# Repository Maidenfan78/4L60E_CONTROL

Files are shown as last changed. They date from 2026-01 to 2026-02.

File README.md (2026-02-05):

# 4L60-E Manual Mode Transmission Controller

Standalone **manual-mode** transmission controller for a GM **4L60-E**, designed to work alongside a **MegaSquirt 3 ECU (MS3 + MS3X)**.

There is **no automatic shifting**.  
All gear changes are commanded directly by the **T-bar range selector (1 / 2 / 3 / D)**.

The system uses:
- **Teensy 4.1** for real-time transmission control
- **Raspberry Pi Zero 2 W** for logging, tuning, and remote access
- **UART** communication between controller and logger. CP2102 USB–TTL adapter

This architecture prioritizes:
- deterministic real-time behavior
- transmission safety
- simplicity and robustness
- extensibility for future features

Pressure switch manifold feedback is strongly recommended as a safety cross-check.

---

## Vehicle / Powertrain

- **Engine:** Holden Alloytec 3.6L V6  
- **ECU:** MegaSquirt 3 + MS3X Expansion  
- **Throttle Body:** Converted from DBW (Drive-by-Wire) to DVC (Drive-by-Cable)  
- **Transmission:** GM 4L60-E (stock valve body)  
- **Shifter:** T-bar (1 / 2 / 3 / D)

---

## Project Goals

- Manual-only gear control
- Stock valve body retained
- Safe EPC (line pressure) control
- Optional torque converter lockup
- Independent transmission operation (no reliance on Pi)
- Logging and configuration via SSH or USB

EPC control assumption for this project: **PWM duty increases EPC current and reduces line pressure**.
Failsafe behavior is **0% duty = max pressure**.

---

## High-Level Architecture

```text
MegaSquirt 3 ECU (TPS / RPM / CAN / Analog)
            |
            v
Teensy 4.1 (TCM / Controller)
- SSA / SSB
- EPC PWM
- TCC enable + TCC PWM
- VSS capture
- Safety + watchdog
            |
            v
          4L60-E

      UART telemetry/config
            |
            v
Raspberry Pi Zero 2 W (Logger/UI)
- SSH
- Logs
- Config
- (optional) UI
```

---

## Documentation Structure

- **README.md** – Project overview (this file)
- **HARDWARE.md** – Electrical architecture, I/O, drivers
- **FIRMWARE.md** – Control logic, state machines, safety rules
- **TODO.md** – Current build plan and next steps
- **CALIBRATION_NOTES.md** – Vehicle-specific sensor calibration data
- **PRESSURE_SWITCH_VERIFICATION.md** – Step-by-step guide to verify pressure switch truth table

---

## Firmware Workspace

Firmware sources and build config live in `firmware/`.

- **PlatformIO** project targeting Teensy 4.1
- Module layout under `firmware/src/` with headers in `firmware/include/`

Build + upload (from repo root):

```bash
pio run -d firmware
pio run -d firmware -t upload
```

---

## Status

Architecture defined.  
Next steps:
- Hardware pin mapping
- Solenoid driver design
- Firmware skeleton

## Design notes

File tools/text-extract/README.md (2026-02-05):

# Text extraction helpers (optional)

These scripts are optional utilities to make `resources/` searchable (QMD or otherwise) by generating `.txt` sidecar files next to PDFs/images.

## PDF -> text (recommended)

Install Poppler (brings `pdftotext`). On Windows you can:
- `choco install poppler` (if you use Chocolatey)
- or download Poppler binaries and add to PATH

Then run:

```powershell
./pdf-to-text.ps1 -Root "C:\Users\Sav\ProgramingProjects\4l60e_control\resources"
```

This creates `*.pdf.txt` files next to each PDF.

## Image -> text (OCR)

Install Tesseract:

```powershell
choco install tesseract
```

Then run:

```powershell
./image-to-text.ps1 -Root "C:\Users\Sav\ProgramingProjects\4l60e_control\resources" -Force
```

Notes:
- OCR quality varies on wiring diagrams. Even rough text helps search.
- Default skip: images > 8MB (tweak with `-MaxFileMb`).

## Notes

- Keep sidecars small and close to source file.
- Don’t overwrite manually curated notes.

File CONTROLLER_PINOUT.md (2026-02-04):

# Controller Connector Pinout

External connector pinout for the 4L60E TCM controller enclosure.
Two panel-mount connectors separate high-current solenoid circuits from low-current signals.

---

## Connector 1 — Transmission (18 pins)

All wires run to/from the transmission case connector, VSS sensor, and pressure switches.
Solenoid returns are low-side MOSFET switched outputs — current flows from the +12V feed through the solenoid and returns through these pins to ground on the PCB.

| Pin | Wire | Direction | Notes |
| --- | ---- | --- | ----- |
| 1 | SSA return | Out | Shift solenoid A, low-side switched |
| 2 | SSB return | Out | Shift solenoid B, low-side switched |
| 3 | EPC return | Out | EPC solenoid, PWM low-side switched |
| 4 | TCC return | Out | TCC solenoid, low-side switched |
| 5 | TCC PWM return | Out | TCC PWM solenoid, PWM low-side switched (diode flyback) |
| 6 | +12V solenoid feed | — | Ignition-switched, fused, to solenoid common |
| 7 | +12V solenoid feed | — | Parallel pin for current capacity |
| 8 | Power ground | — | Solenoid return current path |
| 9 | Power ground | — | Solenoid return current path |
| 10 | Power ground | — | Solenoid return current path |
| 11 | Pressure switch A | In | Ground-switched, 10k pullup to 3.3V on PCB |
| 12 | Pressure switch B | In | Ground-switched, 10k pullup to 3.3V on PCB |
| 13 | Pressure switch C | In | Ground-switched, 10k pullup to 3.3V on PCB |
| 14 | TFT sensor signal | In | NTC thermistor, 4.7k pullup to 3.3V on PCB |
| 15 | Sensor ground | — | TFT, pressure switches, dedicated path |
| 16 | VSS signal | In | VR sensor, AC coupled into LM2903P conditioner |
| 17 | VSS reference | In | VR sensor return (not chassis ground) |
| 18 | Spare | — | Future use (3-2 shift solenoid) |

Total: 17 active + 1 spare

## Connector 2 — Vehicle (16 pins)

All wires run to vehicle-side sources: fuse box, cabin switches, engine sensors, and external peripherals.

| Pin | Wire | Direction | Notes |
| --- | ---- | --- | ----- |
| 1 | +12V ignition power | In | Main controller supply, fused at source |
| 2 | +12V ignition power | In | Parallel pin for current capacity |
| 3 | Power ground | — | Run both to same chassis earth point |
| 4 | Power ground | — | Do not join at connector |
| 5 | Brake switch | In | +12V switched, through 33k/8.2k divider on PCB |
| 6 | TPS signal | In | 0–5V from MS3 TPS wire, through 15k/24k divider on PCB |
| 7 | RPM signal | In | 0–12V square wave from MS3 tach, through 30k/10k divider on PCB |
| 8 | Signal ground | — | Return for TPS, RPM, brake dividers |
| 9 | Range selector 1 | In | Ground-switched, 10k pullup to 3.3V on PCB |
| 10 | Range selector 2 | In | Ground-switched, 10k pullup to 3.3V on PCB |
| 11 | Range selector 3 | In | Ground-switched, 10k pullup to 3.3V on PCB |
| 12 | Range selector D | In | Ground-switched, 10k pullup to 3.3V on PCB |
| 13 | UART TX | Out | Teensy Serial2 TX (3.3V TTL), 1k series resistor on PCB |
| 14 | UART RX | In | Teensy Serial2 RX (3.3V TTL), 1k series resistor on PCB |
| 15 | UART ground | — | Dedicated return for external UART device |
| 16 | Spare | — | Future use |

Total: 15 active + 1 spare

---

## Pin count summary

| Connector | Active | Spare | Total |
| --- | --- | ----- | ----- |
| Transmission | 17 | 1 | 18 |
| Vehicle | 15 | 1 | 16 |
| Overall | 32 | 2 | 34 |

---

## Build notes

### Grounding rules

- **Power grounds** (Conn 1 pins 8–10, Conn 2 pins 3–4): carry solenoid and controller supply current. Run as separate wires all the way to the chassis earth stud — do not join them at or near the connector.
- **Sensor ground** (Conn 1 pin 15): carries only milliamps from TFT, pressure switches. Runs a dedicated wire back to the PCB signal ground. On the PCB, sensor ground and power ground meet at a single star point near the Teensy ground pin.
- **Signal ground** (Conn 2 pin 8): return path for the voltage divider networks (TPS, RPM, brake). Same star-point rule applies on the PCB.
- **UART ground** (Conn 2 pin 15): dedicated return for the external UART device. Joins signal ground at the PCB star point. Do not share this pin with other ground returns at the connector end.

### Solenoid wiring

- The +12V solenoid feed (Conn 1 pins 6–7) goes to the transmission case connector and feeds all solenoids internally through the valve body harness. Fuse this wire (5A) close to the power source. Two pins are used to share the current load — join them at the fuse output, not at the connector.
- Solenoid return wires (Conn 1 pins 1–5) each carry up to ~1.1A when energised. The MOSFETs on the PCB switch these to ground.
- TCC PWM return (Conn 1 pin 5) is the progressive converter clutch apply solenoid. Uses PWM low-side switching with diode flyback (same topology as EPC) for smooth engagement.
- When all solenoids are off (SSA OFF, SSB OFF), the transmission defaults to 3rd gear (GM failsafe). This is the safe power-loss state.

### VSS sensor

- The VR sensor is a two-wire AC source — it is NOT ground-referenced. Run both VSS signal and VSS reference as a twisted pair from the sensor to the connector. Do not ground the VSS reference wire to chassis at the transmission end.

### UART breakout

- The external UART port uses Teensy Serial2 (TX2/RX2), independent of the internal Pi-Teensy link on Serial1.
- 3.3V TTL levels only. If connecting to a 5V device, use an external level shifter.
- 1k series resistors on both TX and RX are on the PCB for protection.
- Suitable for: USB-TTL debug adapter, Bluetooth serial module (HC-05/06), dash data logger, or external display.
- Default baud rate: TBD (match firmware Serial2 configuration).

### Input protection

- All external-voltage inputs (brake 12V, TPS 5V, RPM 12V) have resistor dividers and dual BAT85 Schottky clamps on the PCB. The connector carries the raw signal — all conditioning happens on the board.
- Ground-switched inputs (range selector, pressure switches) have 10k pullups to 3.3V on the PCB. The connector just passes the switch wire through.

### Wire gauge recommendations

- Solenoid returns + 12V feed: 18–20 AWG (rated for ~1A continuous per wire)
- Power supply + grounds: 18 AWG minimum (multiple amps through controller supply)
- Sensor and signal wires: 22–24 AWG (milliamp currents)
- VSS twisted pair: 22 AWG shielded (noise rejection for VR sensor)
- UART wires: 22–24 AWG (milliamp currents, keep under 2m for reliable comms)

### Connector selection

- Panel-mount (bulkhead) type connectors rated for automotive vibration.
- Transmission connector (18-pin): 5A+ per pin minimum (solenoid current).
- Vehicle connector (16-pin): 3A+ per pin sufficient (mostly signal level).
- Deutsch DTM or DT series panel-mount are the industry standard for aftermarket ECUs. GX20 aviation style connectors are a cheaper alternative.
- Always use keyed/polarised connectors — a mis-mated plug on a transmission controller can destroy solenoids or the PCB.

### Spare pins

- One spare on the transmission connector allows adding the 3-2 shift solenoid later without changing connectors.
- One spare on the vehicle connector for future expansion (e.g. boost solenoid signal, shift light output).

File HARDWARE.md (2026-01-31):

# Hardware Design – 4L60-E Manual Controller

This document describes the electrical and hardware architecture of the transmission controller.

---

## Core Components

### Real-Time Controller
- **Teensy 4.1**
- 600 MHz ARM Cortex-M7
- 3.3V logic
- Hardware PWM timers
- Interrupt-based VSS capture
- Watchdog support

### Logger / Interface
- **Raspberry Pi Zero 2 W**
- Wi-Fi + Bluetooth
- SSH access
- SD-card based logging
- Optional web UI

---

## Power Architecture

- Vehicle 12V supply (10V cranking to 14.7V charging, transients to 40V+)
- Input protection: F1 (2A fuse) → D1 (VFT4045BP Schottky, reverse polarity) → TVS1 (P6KE18A, transient clamp)
- Separate regulated outputs:
  - **PS1: OKI-78SR-5/1.5-W36E-C** → 5V / 1.5A → Teensy 4.1 VIN + line pressure sensor
  - **PS2: DFR0831** → 5V / 4A → Raspberry Pi Zero 2 W (via GPIO header Pin 2/4)
- Both converters need ≥7V input (≥7.4V at battery after Schottky drop)
- Pi powered through GPIO header, not micro USB (bypasses polyfuse; F1 provides upstream protection)

The Teensy must continue running if the Pi browns out or resets.

---

## Communication

- **Protocol:** UART (3.3V TTL)
- **Baud rate:** TBD (e.g. 115200)
- **Direction:**
  - Teensy → Pi: telemetry
  - Pi → Teensy: validated config updates (optional)

CAN may be added later but is not required.

---

## Transmission Outputs (from Teensy)

All solenoids are driven via **automotive-rated low-side drivers**.

| Output | Function |
|---|---|
| SSA | Shift Solenoid A |
| SSB | Shift Solenoid B |
| EPC | Line pressure control (PWM) |
| TCC | Torque converter clutch (on/off enable) |
| TCC PWM | Progressive converter clutch apply (PWM) |

> Solenoids must **never** be driven directly from MCU pins.

---

## Required Inputs to the Controller

### Mandatory
- **Range Selector** (1 / 2 / 3 / D)
- **Vehicle Speed Sensor (VSS)**
- **Throttle Position (TPS)**  
  (from MS3, analog 0–5V or CAN)
- **Brake Switch**

### Strongly Recommended. These are 100% confirmed to be included.
- **Transmission Temperature Sensor**
- **Engine RPM** (from MS3)
- **Pressure switch manifold** (gear confirmation diagnostics)

### Optional / Future
- Paddle shifters
- Mode selector (street / firm / valet)

---

## Shift Solenoid Truth Table (4L60-E)

| Gear | SSA | SSB |
|-----|-----|-----|
| 1st | ON  | ON  |
| 2nd | OFF | ON  |
| 3rd | OFF | OFF |
| 4th | ON  | OFF |

---

## Hardware Design Notes

- EPC solenoid requires **stable PWM** and sufficient current capacity
- Grounding must be low-impedance and star-routed
- VSS input should be protected and conditioned
- All outputs default to a **safe state** on MCU reset

--- 

## Safety Philosophy

- Loss of logger/UI must not affect transmission control
- Any invalid sensor state → increased line pressure
- Harsh shifts are preferred over clutch slip

---

## Signal Levels & Conditioning

- **VSS**: VR sensors need a conditioner (comparator/zero-cross). Hall sensors can be direct with pull-up.
- **TPS / Line Pressure (0–5V)**: scale to 0–3.3V using a divider (e.g., 15k/24k) and add Schottky clamp diodes + a small series resistor at the MCU pin.
- **Brake / 12V Inputs**: use a divider sized for 15V max (e.g., 47k/12k), plus series resistor and Schottky clamps to 3.3V/GND.

---

Teensy 4.1 – Pin Assignment Table

4L60-E Manual Mode Transmission Controller

Digital Outputs (Solenoids)
Function	Teensy Pin	Type	Notes
Shift Solenoid A (SSA)	Pin 2	Digital OUT	Low-side driver input
Shift Solenoid B (SSB)	Pin 3	Digital OUT	Low-side driver input
Torque Converter Clutch (TCC)	Pin 4	Digital OUT	On/off enable
TCC PWM (Progressive Apply)	Pin 12	PWM OUT	Hardware PWM, smooth lockup
EPC / PCS (Line Pressure)	Pin 5	PWM OUT	Hardware PWM, critical

Why these pins

All are on the same GPIO bank

Clean hardware PWM available on Pin 5

Easy to scope during testing

Digital Inputs
Function	Teensy Pin	Type	Notes
Range Selector – 1	Pin 6	Digital IN	Pulled-up, grounded when active
Range Selector – 2	Pin 7	Digital IN	〃
Range Selector – 3	Pin 8	Digital IN	〃
Range Selector – D	Pin 9	Digital IN	〃
Brake Switch	Pin 10	Digital IN	Active high or low (configurable)
Watchdog / Enable (optional)	Pin 11	Digital IN	Optional safety input

Range selector assumed to be decoded into discrete signals
(preferred over analog decoding for reliability).

Pressure Switch Manifold (Gear Confirmation)
Function	Teensy Pin	Type	Notes
Pressure Switch A	Pin 20	Digital IN	Pulled-up, active low
Pressure Switch B	Pin 21	Digital IN	Pulled-up, active low
Pressure Switch C	Pin 22	Digital IN	Pulled-up, active low

Used for gear confirmation diagnostics and fault detection.

Analog Inputs
Function	Teensy Pin	ADC	Notes
TPS (from MS3)	A0 (Pin 14)	ADC1	0–5V scaled to 3.3V
Transmission Temp	A1 (Pin 15)	ADC1	NTC with pull-up
Optional Line Pressure Sensor	A2 (Pin 16)	ADC1	Future expansion

⚠️ Important:
Teensy 4.1 is 3.3V max on ADC pins.
Any 0–5V signal must be divided or buffered.

Speed / Timing Inputs
Function	Teensy Pin	Type	Notes
Vehicle Speed Sensor (VSS)	Pin 18	Interrupt IN	VR → conditioner, Hall → direct
Engine RPM (optional)	Pin 19	Interrupt IN	From MS3 tach out

Pins 18/19 are ideal because:

Dedicated interrupt capability

High-speed edge capture

Minimal latency

Communication
Function	Teensy Pins	Interface	Notes
UART to Pi	TX1 (Pin 1)	Serial1 TX	Teensy → Pi
UART to Pi	RX1 (Pin 0)	Serial1 RX	Pi → Teensy
USB	USB Port	USB CDC	Firmware + bench testing

UART is preferred in-vehicle.
USB is bench/debug only.

Power & Ground
Signal	Connection	Notes
VIN	5V Regulated	From automotive buck
GND	Star Ground	Shared with drivers
AGND	Sensor Ground	TPS / temp reference
Default Output States (Fail-Safe)
Output	Reset State	Reason
SSA	OFF	Prevent unintended shift
SSB	OFF	Prevent unintended shift
EPC	OFF (0% duty)	Max pressure (project assumption)
TCC	OFF	Prevent stall
TCC PWM	OFF (0% duty)	No progressive apply

These defaults must be enforced in firmware AND hardware pull states.
SSA/SSB OFF corresponds to a 3rd-gear command; this is the defined failsafe gear.

Pin Usage Summary
Category	Pins Used
Digital Outputs	2, 3, 4, 5, 12
Digital Inputs	6–11, 20–22
Analog Inputs	14–16
Interrupt Inputs	18, 19
UART	0, 1

Plenty of pins remain free for:

CAN

paddles

mode switch

pressure sensor

diagnostics LEDs

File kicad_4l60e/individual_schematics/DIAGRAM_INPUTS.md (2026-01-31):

# Input Conditioning Circuits

All outputs go to Teensy 4.1 (3.3V absolute max on GPIO).
For external signals, use divider + series resistor + Schottky clamp diodes to keep pins safe.
Automotive voltage range: 10V cranking, 12.6V resting, 14.7V charging (design for 15V worst case).

## Diagrams (SVG)

- `kicad_4l60e/input_diagrams/tps_input.svg`
- `kicad_4l60e/input_diagrams/brake_input.svg`
- `kicad_4l60e/input_diagrams/trans_temp_input.svg`
- `kicad_4l60e/input_diagrams/line_pressure_input.svg`
- `kicad_4l60e/input_diagrams/rpm_input.svg`
- `kicad_4l60e/input_diagrams/range_selector_input.svg`
- `kicad_4l60e/input_diagrams/pressure_switches_input.svg`
- `kicad_4l60e/vss_input_schematic.svg` (VR VSS)

---

## TPS (Pin A0) - Throttle Position Sensor, 0-5V

```
TPS_IN (0-5V) ---[15k]---+---[24k]--- GND
                          |
                          +---[0.1uF]--- GND
                          |
                          +---[1k]---+--- MCU_TPS_A0
                                   |
                                 [D1] 1N5817 (clamp to GND)
                                   |
                                  GND
                                   |
                                 [D2] 1N5817 (clamp to +3.3V)
                                   |
                                 +3.3V
```
Divider: 24k/(24k+15k) = 0.615 --> 5V in = 3.08V out, 5.25V = 3.23V
Filter: ~100Hz cutoff with 10k and 0.1uF

---

## Brake Switch (Pin 10) - 12V Switched

One side of switch wired to +12V (battery/ignition), other side to TCM input.

```
+12V --- [brake switch] ---[47k]---+---[12k]--- GND
                                   |
                                   +---[1k]---+--- MCU_BRAKE_D10
                                             |
                                           [D3] 1N5817 (clamp to GND)
                                             |
                                            GND
                                             |
                                           [D4] 1N5817 (clamp to +3.3V)
                                             |
                                           +3.3V
```
Divider: 12k/(12k+47k) = 0.203

| Condition | Vin | MCU sees | Logic |
|---|---|---|---|
| Brake OFF | 0V | 0V | LOW |
| Brake ON (cranking) | 10V | 2.03V | HIGH  |
| Brake ON (running) | 14.7V | 2.98V | HIGH  |
| Brake ON (worst case)  | 15V | 3.05V | HIGH  |

All values under 3.3V max. Cranking still reads as solid HIGH.

---

## Trans Temp (Pin A1) - NTC Thermistor

```
+3.3V
  |
[3.3k]  pullup
  |
  +---[0.1uF]--- GND
  |
  +--- MCU_TTEMP_A1
  |
 NTC (from trans)
  |
 GND
```
3.3k pullup + NTC forms voltage divider.
Cold = high resistance = high voltage. Hot = low resistance = low voltage.

Connector (2-pin): Pin 1 = NTC signal, Pin 2 = GND

---

## Line Pressure (Pin A2) - Optional Pressure Transducer

Sensor is 5V powered, outputs 0.5-4.5V. 4.5V exceeds 3.3V max so a divider is needed.

```
+5V ------------ J_LPRESS Pin 1 (sensor power)

Sensor signal --- J_LPRESS Pin 2 ---[15k]---+---[24k]--- GND
(0.5-4.5V)                                  |
                                             +---[0.1uF]--- GND
                                             |
                                             +---[1k]---+--- MCU_LPRESS_A2
                                                       |
                                                     [D5] 1N5817 (clamp to GND)
                                                       |
                                                      GND
                                                       |
                                                     [D6] 1N5817 (clamp to +3.3V)
                                                       |
                                                     +3.3V

GND ------------ J_LPRESS Pin 3 (sensor ground)
```
Divider: 24k/(24k+15k) = 0.615

| Sensor output | MCU sees |
|---|---|
| 0.5V (0 psi)  | 0.31V |
| 2.5V (mid) | 1.54V |
| 4.5V (max) | 2.77V |
| 5.0V (fault)  | 3.08V |

All values under 3.3V max. Filter: ~100Hz cutoff with 10k and 0.1uF.

Connector (3-pin): Pin 1 = +5V, Pin 2 = Signal, Pin 3 = GND

---

## RPM (Pin 19) - Tach from MegaSquirt 3

MS3 tach output is a 0-12V square wave (battery-level). Use a voltage divider to bring it under 3.3V,
then clamp diodes as backup protection.

```
RPM_IN (0-12V sq) ---[47k]---+---[12k]--- GND
                              |
                              +---[1k]---+--- MCU_RPM_D19
                                        |
                                      [D7] 1N5817 (clamp to GND)
                                        |
                                       GND
                                        |
                                      [D8] 1N5817 (clamp to +3.3V)
                                        |
                                      +3.3V
```
Divider: 12k/(12k+47k) = 0.203 --> 12V in = 2.44V out
Schottky clamp diodes are backup only - divider does the real work.
Square wave at ~2.4V is a solid logic HIGH.

Connector (2-pin): Pin 1 = RPM signal, Pin 2 = GND

---

## Range Selector (Pins 6/7/8/9) - T-Bar 1/2/3/D

Each range position has its own wire from the TCM to the switch.
All switches share a common ground on the other side.
Selecting a gear grounds that wire.

```
+3.3V  +3.3V  +3.3V  +3.3V
  |      |      |      |
[10k]  [10k]  [10k]  [10k]   external pullups
  |      |      |      |
  +------+------+------+----- J_RANGE Pin 5 (common GND on switch side)
  |      |      |      |             |
  |      |      |      |           (GND)
  |      |      |      |
  |      |      |      +--- MCU_RNGD_D9  (Drive/4th)
  |      |      +--- MCU_RNG3_D8         (3rd)
  |      +--- MCU_RNG2_D7                (2nd)
  +--- MCU_RNG1_D6                       (1st)
```

Better view - each channel is identical:

```
+3.3V ---[10k]---+--- MCU_RNGx
                  |
           Range switch (normally open)
                  |
                 GND (common ground at switch)
```

- Switch OPEN  = 10k pulls pin HIGH (3.3V) = not selected
- Switch CLOSED = pin pulled to GND          = gear selected
- Only one position active at a time

Connector (5-pin): Pin 1 = Gear 1, Pin 2 = Gear 2, Pin 3 = Gear 3, Pin 4 = Drive, Pin 5 = Common GND

---

## Pressure Switches A/B/C (Pins 20/21/22) - Gear Confirmation

Same topology as range selector. Trans internal switches are ground-switched.

```
+3.3V ---[10k]---+--- MCU_PSW_x
                  |
           Pressure switch (inside trans)
                  |
                 GND (common ground)
```

- Switch OPEN  = HIGH = pressure not present
- Switch CLOSED = LOW  = pressure present

Connector (4-pin): Pin 1 = PSW_A, Pin 2 = PSW_B, Pin 3 = PSW_C, Pin 4 = Common GND

---

## VSS (Pin 18) - Variable Reluctance Speed Sensor with LM2903P

```
                    +3.3V             +3.3V
                     |                   |
                    [10k] bias        [10k] pullup
                     |                   |
VR sensor ---[0.1uF]-+---[D2]---+3.3V    |
  (AC)               |              LM2903P OUT (Pin 1) ---+--- MCU_VSS_D18
                     +---[D1]---GND     |                  |
                     |                  |                [0.1uF] C4
                   [10k] bias       [100k]                 |
                     |              hysteresis             GND
                    GND                |
                     |                 |
                     +--- LM2903P IN(+) Pin 3 -+
                     |
                     +--- LM2903P IN(-) Pin 2 --- same bias point (1.65V)

                    +3.3V (Pin 8)
                       |
                     [0.1uF] C5 (decoupling cap, close to IC)
                       |
                      GND (Pin 4)
```

**LM2903P DIP-8 Pinout:**

- Pin 1: Output (comparator 1) → to MCU via pullup
- Pin 2: IN(-) → 1.65V reference
- Pin 3: IN(+) → biased VR signal
- Pin 4: GND
- Pin 5: IN(+) comparator 2 (NC)
- Pin 6: IN(-) comparator 2 (NC)
- Pin 7: Output comparator 2 (NC)
- Pin 8: VCC (+3.3V)

**Step by step:**

1. **AC coupling**: C3 = 0.1uF blocks DC from VR sensor, passes AC signal
2. **Clamp diodes**: D1 (1N4148) to GND, D2 (1N4148) to +3.3V - limits swing
3. **Bias network**: Two 10k resistors, one to +3.3V and one to GND = 1.65V DC bias
4. **Comparator (-) input (Pin 2)**: Tied to same 1.65V bias point (reference)
5. **Comparator (+) input (Pin 3)**: Biased VR signal - swings above/below 1.65V
6. **Hysteresis**: R9 = 100k from output back to (+) input prevents chatter
7. **Output pullup**: R10 = 10k to +3.3V (LM2903 is open-collector, needs pullup)
8. **Output filter**: C4 = 0.1uF on output cleans up edges
9. **Power**: Pin 8 to +3.3V, Pin 4 to GND, C5 = 0.1uF decoupling cap between them

Connector (2-pin): Pin 1 = VR signal, Pin 2 = VR return / GND

For Hall-effect VSS: skip this circuit, just use 10k pullup to 3.3V directly.

---

## Component Summary

| Part | Value | Qty | Used In |
|---|---|-----|---|
| R | 1k | 4 | Series resistors for TPS, RPM, line pressure, brake |
| R | 10k | 10  | Range (x4), pressure sw (x3), VSS pullup, VSS bias (x2) |
| R | 12k | 2 | Brake divider, RPM divider (bottom resistor) |
| R | 15k | 2 | TPS divider, line pressure divider (top resistor) |
| R | 24k | 2 | TPS divider, line pressure divider (bottom resistor) |
| R | 47k | 2 | Brake divider, RPM divider (top resistor) |
| R | 3.3k | 1 | Temp pullup |
| R | 100k | 1 | VSS hysteresis |
| C | 0.1uF | 6 | TPS, temp, line pressure, VSS coupling (C3), VSS output (C4), VSS decoupling (C5) |
| D | 1N5817  | 8 | TPS clamp (x2), RPM clamp (x2), line pressure clamp (x2), brake clamp (x2) |
| D | 1N4148  | 2 | VSS clamp (x2) |
| IC | LM2903P | 1 | VSS comparator (DIP-8, only comparator 1 used) |

## Pin Summary

| Teensy Pin | Function | Type |
|---|---|---|
| A0 (14) | TPS | Analog 0-3.3V |
| A1 (15) | Trans Temp | Analog (NTC) |
| A2 (16) | Line Pressure | Analog 0.5-4.5V (optional) |
| 6 | Range 1st | Digital, active LOW |
| 7 | Range 2nd | Digital, active LOW |
| 8 | Range 3rd | Digital, active LOW |
| 9 | Range Drive | Digital, active LOW |
| 10 | Brake Switch | Digital, active HIGH |
| 18 | VSS | Digital, interrupt |
| 19 | RPM Tach | Digital, frequency |
| 20 | Pressure Sw A | Digital, active LOW |
| 21 | Pressure Sw B | Digital, active LOW |
| 22 | Pressure Sw C | Digital, active LOW |

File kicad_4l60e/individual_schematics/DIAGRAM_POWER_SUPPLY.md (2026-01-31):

# Power Supply Circuits

Automotive 12V to regulated 5V for Teensy 4.1 and Raspberry Pi Zero 2 W.
Automotive voltage range: 10V cranking, 12.6V resting, 14.7V charging, transients to ~40V.

---

## Power Architecture Overview

```
                                        +--- OKI-78SR-5 ---+--- 5V_TEENSY ---> Teensy 4.1 VIN
                                        |   (5V / 1.5A)    |
VEHICLE +12V ---[F1]---[D1]---[TVS1]---+                   +--- 5V_SENSOR ---> Line pressure sensor
                                        |
                                        +--- DFR0831 ------+--- 5V_PI -------> Pi Zero 2 W
                                            (5V / 4A)

VEHICLE GND -------------------------------- GND (star ground point)
```

Key design rules:
- Teensy and Pi have **separate** buck converters (Teensy must survive Pi brownout)
- Reverse polarity protection **before** both converters
- TVS clamping **before** both converters
- Fuse protects the entire board

---

## Stage 1: Input Protection

```
VEHICLE +12V                                         To buck converters
    |                                                       |
    +---[F1 2A fast-blow]---+---[D1 VFT4045BP]-----+--------+
                            |    (Schottky)        |
                            |    Anode --> Cathode |
                            |                      |
                            |                   [TVS1]  P6KE18A (or SMBJ16A)
                            |                      |
                           GND                    GND
```

### F1 - Input Fuse
- **2A fast-blow** fuse
- Protects against short circuits and reverse polarity (blows if D1 is reverse-biased)
- OKI-78SR datasheet recommends 2A fuse

### D1 - Reverse Polarity Protection (VFT4045BP Schottky)
- 45V, 40A Schottky rectifier
- Forward voltage drop: **0.41V** at 5A (very low loss)
- At 1A typical system draw: ~0.3V drop, so converters see ~12.3V (well above 7V min)
- At cranking (10V): converters see ~9.6V (still above 7V min)
- Blocks reverse polarity completely (fuse blows as backup)

### TVS1 - Transient Voltage Suppression
- **P6KE18A** (or SMBJ16A bidirectional)
- Standoff voltage: 15.3V (won't conduct during normal operation at 14.7V)
- Breakdown: 18V
- Clamps load dump transients (up to 40V+ spikes) to safe levels
- Placed **after** D1 so it only sees forward-polarity transients

### Voltage at converter inputs after protection:

| Condition | Battery | After D1 (Schottky) | TVS clamp |
|---|---|---|---|
| Cranking | 10V | ~9.6V | No clamp  |
| Resting | 12.6V | ~12.2V | No clamp  |
| Charging | 14.7V | ~14.3V | No clamp  |
| Load dump spike | 40V+ | ~39.6V | Clamped to ~18V |

All values within OKI-78SR input range (7-36V).

---

## Stage 2A: Teensy 4.1 Power Supply

```
Protected 12V rail                              To Teensy 4.1
      |                                              |
      +---[Cin 22uF ceramic]---GND          +--------+---[Cout 22uF ceramic]---GND
      |                                     |
      +--- OKI-78SR-5/1.5-W36E-C ---+------+
           Pin 1: +Vin               |
           Pin 2: GND (Common)       |
           Pin 3: +Vout (5V)         |
                                     |
                              5V_TEENSY rail
                                     |
                                     +---> Teensy 4.1 VIN pin
                                     +---> Line pressure sensor +5V (if used)
```

### OKI-78SR-5/1.5-W36E-C
- Input: 7-36V DC (covers full automotive range after Schottky drop)
- Output: **5.0V regulated**, 1.5A max
- Efficiency: ~90% at 12V in
- Short circuit protection (hiccup mode, auto-recovery)
- No heatsink required
- Drop-in replacement for 7805 linear regulator (same pinout)
- Operating temp: -40 to +85C

### Input capacitor (Cin)
- 22uF ceramic, 50V rated
- Placed close to OKI-78SR input pins
- Low ESR type (X5R or X7R)
- Per datasheet: "install a low-ESR capacitor immediately adjacent to input terminals"

### Output capacitor (Cout)
- 22uF ceramic, 10V rated
- Optional per datasheet but recommended for improved transient response
- Do NOT exceed 300uF (low ESR) or 3300uF (higher ESR)

### Load budget (Teensy rail):

| Load | Current |
|---|---|
| Teensy 4.1 | ~100mA |
| Input conditioning (3.3V) | ~5mA |
| LM2903 comparator | ~2mA |
| Line pressure sensor | ~20mA |
| **Total** | **~130mA** |

Well within 1.5A capacity. Teensy's onboard regulator converts 5V to 3.3V for the MCU and I/O.

---

## Stage 2B: Raspberry Pi Power Supply

```
Protected 12V rail                              To Pi Zero 2 W
      |                                              |
      +---[Cin 22uF ceramic]---GND                   |
      |                                     +--------+
      +--- DFR0831 ---- OUT+ ---+-----------+
           IN+                  |            |
           IN-                  |        Pi GPIO Header
           OUT-                 |        Pin 2/4 = +5V
             |                  |        Pin 6 = GND
            GND                 |
                           [Cout2 220uF electrolytic]
                                |
                               GND
```

### DFR0831 DC-DC Buck Converter
- Input: 7-24V DC
- Output: **5.0V regulated**, 4A max (20W)
- Efficiency: ~90%
- Output ripple: <100mV
- Output accuracy: +/-0.1V
- Operating temp: -40 to +85C
- 6 output ports on board (convenient for Pi + accessories)

### Output bulk capacitor (Cout2)

- 220uF electrolytic, 10V rated
- Smooths transient current demands from the Pi (draws current in bursts during boot and CPU/USB activity)
- The DFR0831's onboard caps are small ceramics — the bulk cap supplements them
- Not strictly required but cheap insurance in an automotive environment

### Pi Zero 2 W connection

- Power via **GPIO header** (not micro USB port)
- Pin 2 or Pin 4 = +5V, Pin 6 = GND
- This bypasses the Pi's onboard polyfuse, so the DFR0831's current limit and upstream fuse F1 provide protection
- UART connection to Teensy: Pi GPIO 14 (TX) → Teensy RX1 (Pin 0), Pi GPIO 15 (RX) → Teensy TX1 (Pin 1)
- Both are 3.3V logic — no level shifting needed

### Important note on input range

- DFR0831 max input is **24V** (30V absolute max on PCB marking)
- The TVS clamps transients to ~18V so this is safe
- At charging voltage (14.7V - 0.4V Schottky = 14.3V): well within range
- Without the TVS, automotive load dump could exceed 24V and damage this converter

### Load budget (Pi rail):

| Load | Current |
|---|---|
| Pi Zero 2 W (idle)  | ~100mA |
| Pi Zero 2 W (busy)  | ~350mA |
| Pi Zero 2 W (peak)  | ~500mA |
| Wi-Fi active | +50-100mA  |
| **Total peak** | **~600mA** |

Well within 4A capacity.

---

## Stage 3: Teensy Power Input Detail

```
5V_TEENSY rail
      |
      +---> Teensy 4.1 VIN pin (regulated 5V input)

      Teensy onboard:
      VIN (5V) ---> [onboard 3.3V regulator] ---> 3.3V rail (250mA max)
                                                     |
                                                     +---> MCU (i.MX RT1062)
                                                     +---> GPIO pins (3.3V logic)
                                                     +---> 3.3V output pin
                                                              |
                                                              +---> Input pullups
                                                              +---> VSS bias network
                                                              +---> LM2903 Vcc
```

The Teensy's **onboard 3.3V regulator** supplies:
- The MCU itself
- All GPIO pins (3.3V logic)
- The 3.3V output pin that powers our input conditioning pullups and bias networks
- Total 3.3V load from our circuits: ~5mA (well under 250mA capacity)

---

## Grounding

```
                    STAR GROUND POINT (single PCB location)
                            |
              +-------------+-------------+-------------+
              |             |             |             |
         Power GND     Signal GND    Analog GND    Solenoid GND
              |             |             |             |
         Buck converter  Digital I/O   TPS/Temp ADC   MOSFET drivers
         returns         range sel.    NTC sensor     SSA/SSB/EPC/TCC
                         press. sw.    line pressure
                         brake sw.     VSS bias
```

### Grounding rules:
1. **Single star ground point** on PCB - all ground paths meet here
2. **Analog ground (AGND)** traces kept separate from digital until star point
3. **Solenoid return currents** routed separately - high current PWM noise must not
   couple into signal grounds
4. Teensy AGND pin tied to analog ground trace
5. Teensy GND pins tied to digital/power ground
6. Both connect at the star point

---

## Component Summary

| Part | Value / Part Number | Qty | Function |
|---|---|-----|---|
| F1 | 2A fast-blow fuse | 1 | Input overcurrent protection |
| D1 | VFT4045BP (Schottky) | 1 | Reverse polarity protection |
| TVS1 | P6KE18A | 1 | Transient voltage clamping |
| U_REG1 | OKI-78SR-5/1.5-W36E-C | 1 | 12V to 5V buck (Teensy) |
| U_REG2 | DFR0831 | 1 | 12V to 5V buck (Pi) |
| Cin1 | 22uF ceramic 50V | 1 | OKI-78SR input filter |
| Cout1 | 22uF ceramic 10V | 1 | OKI-78SR output filter |
| Cin2 | 22uF ceramic 50V | 1 | DFR0831 input filter |
| Cout2 | 220uF electrolytic 10V | 1 | DFR0831 output bulk cap |

---

## Cranking / Brownout Behavior

| Event | Battery V | After D1 | OKI-78SR (Teensy) | DFR0831 (Pi) |
|---|---|---|---|---|
| Normal running | 14.0V | 13.6V | 5.0V output OK | 5.0V output OK |
| Key on, engine off | 12.6V | 12.2V | 5.0V output OK | 5.0V output OK |
| Cranking dip | 10.0V | 9.6V | 5.0V output OK | 5.0V output OK |
| Deep crank | 7.5V | 7.1V | 5.0V output OK (min 7V) | 5.0V output OK (min 7V) |
| Severe brownout | 6.5V | 6.1V | **Drops out** | **Drops out** |

Both converters have 7V minimum input. After the ~0.4V Schottky drop, the system needs at
least **7.4V at the battery** to maintain regulation. Below that, both converters will drop out.

The OKI-78SR has hiccup-mode short circuit protection and will auto-recover when voltage
returns. The Teensy will reboot cleanly on power restore.

If the Pi browns out first (due to higher current draw), the Teensy continues running
independently - this is by design. The transmission controller does not depend on the Pi.

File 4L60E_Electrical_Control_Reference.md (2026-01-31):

# 4L60‑E Electrical & Control Reference  
**Solenoids, Sensors, PWM, and Calibration Notes**

This document is a **supplemental technical reference** for a GM **4L60‑E** automatic transmission, intended to be used alongside wiring/pinout documentation.

It focuses on:
- solenoid electrical characteristics
- PWM requirements
- sensor ranges
- practical control notes for standalone controllers (Teensy, MegaShift, etc.)

---

## 1) Solenoid Electrical Characteristics

| Solenoid | Function | Resistance (Ω) | Typical Current | Control Type |
|---|---|---|---|---|
| Shift Solenoid A (SSA) | 1–2 / 3–4 shifts | 20–40 Ω | ~0.5–0.8 A | On/Off |
| Shift Solenoid B (SSB) | 2–3 shifts | 20–40 Ω | ~0.5–0.8 A | On/Off |
| 3–2 Control Solenoid | Coast downshift assist | 9–14 Ω | ~1.0–1.3 A | PWM |
| EPC / PCS Solenoid | Line pressure control | **3.5–4.6 Ω** | **0–1.1 A** (0A=max pressure) | **PWM (critical)** |
| TCC Solenoid | Torque converter lockup (enable) | 20–40 Ω | ~1.0–1.5 A | On/Off |
| TCC PWM Solenoid | Progressive converter clutch apply | 20–40 Ω | ~1.0 A | PWM |
| LUF (if fitted) | Lockup feel modulation | ~10–15 Ω | ~1.0 A | PWM |

**Notes**
- All solenoids are **ground‑switched** (low‑side control).
- EPC solenoid has the **highest thermal load** and must be heatsinked.
- Resistance varies by year/manufacturer; measure if in doubt.

---

## 2) Recommended PWM Frequencies

| Solenoid | PWM Frequency | Notes |
|---|---|---|
| EPC / PCS | **200–300 Hz** (OEM ≈ 293 Hz) | Higher = heat, lower = noise |
| 3–2 Solenoid | ~50 Hz | Only active during coast downshifts |
| LUF | ~30–40 Hz | Optional / transmission dependent |
| TCC (if PWM) | 20–100 Hz | Often used as on/off |

For EPC (exhaust-bleed type):

- Duty cycle ↑ → line pressure ↓ (exhaust open longer)
- Duty cycle ↓ → line pressure ↑ (exhaust open shorter)
- 0% duty = max pressure (failsafe)
- **60% duty is the hard ceiling** — not a comfort limit, but thermal + hydraulic protection
  - At ~4Ω coil resistance, 60% duty limits average current to ~1.1A
  - Never exceed 60% duty even when requesting minimum pressure

---

## 3) EPC (Line Pressure) Control Guidelines

### Pressure Command Abstraction (Recommended)

Use a **Pressure Command %** scale in firmware (0–100%, where 100% = max pressure).
Convert to EPC duty via inversion in one place:

| Pressure Command | EPC Duty (approx) | Result |
|---|---|---|
| 100% (max) | ~5% (near OFF) | Maximum pressure |
| 50% | ~30% | Medium pressure  |
| 0% (min) | ~60% (near max) | Minimum pressure |

This keeps tuning tables intuitive and matches MegaShift conventions.

### Control Rules

- EPC duty must **never rise too high under load** (causes low pressure / slip)
- Conservative tuning is preferred:
  - harsh shifts > clutch slip
- Use a **shift pressure bump**:
  - temporarily raise pressure command during gear changes
- On fault:
  - force **100% pressure command** (0% EPC duty = max pressure)
  - disable TCC

### Typical Pressure Command Ranges

| Condition | Pressure Command |
|---|---|
| Light load cruise| ~30–40% |
| Moderate load | ~45–55% |
| Heavy load / WOT | ~60–75% |
| Shift bump | +15–25% |

(Exact values depend on valve body and calibration.)

### Flyback Suppression for EPC

For **smoother pressure modulation**, use a **diode** (e.g., 1N4001) across the EPC solenoid.
The slower current decay acts as a low-pass filter on pressure changes.

For **SSA/SSB/TCC enable** (on/off solenoids), use **TVS** for faster response.
For **TCC PWM**, use a **diode** (same as EPC) for smooth progressive apply.

---

## 4) Transmission Sensors

### 4.1 Vehicle Speed Sensor (VSS)
- Type: usually **2‑wire VR**
- Signal: AC sine wave
- Requires zero‑crossing or comparator conditioning
- Frequency proportional to output shaft speed

Standalone controllers must:
- condition VR properly
- debounce / filter noise
- detect signal loss

---

### 4.2 Transmission Temperature Sensor
- Type: NTC thermistor (GM style)
- Typical resistance:
  - ~100kΩ cold
  - ~2–5kΩ hot
- Used for:
  - TCC inhibit
  - pressure biasing
  - over‑temp protection

---

### 4.3 Line Pressure Sensor (optional)
- Type: 0.5–4.5 V transducer
- Supply: 5 V reference
- Range: commonly 0–300 psi
- Very useful for EPC tuning

---

### 4.4 Pressure Switch Manifold (Manual Valve Position)

The pressure switches report hydraulic state of the manual valve.

| Gear | Switch A | Switch B | Switch C |
|----|----|----|----|
| 1st | 0 | 1 | 1 |
| 2nd | 1 | 1 | 1 |
| 3rd | 1 | 1 | 0 |
| 4th | 1 | 0 | 0 |
| Reverse | 0 | 0 | 1 |
| Neutral / Park | 0 | 0 | 0 |

These can be used as:
- sanity checks
- limp‑mode detection
- diagnostics

---

## 5) TCC (Torque Converter Clutch) Notes

- Lockup only recommended in **3rd and 4th**
- Always unlock:
  - during shifts
  - on brake input (immediate)
  - at high TPS
  - during throttle transients
  - during faults
- Use **delay timer before lockup** — prevents lock/unlock cycling
- Hysteresis matters more than fancy logic
- TCC must never fight EPC or gear changes
- TCC PWM progressive apply ramps clutch pressure gently to avoid shudder
- TCC enable (on/off) energises first, then TCC PWM ramps up
- On unlock: TCC PWM drops to 0% immediately, then TCC enable turns off

---

## 6) Electrical & Grounding Notes

- Solenoids must have:
  - dedicated high‑current ground returns
  - separate sensor ground
- Avoid shared grounds between:
  - EPC return
  - TPS / temp sensors
- Use star grounding at controller enclosure

---

## 7) Standalone Controller Safety Rules (Recommended)

- Default state on reset:
  - SSA OFF, SSB OFF (3rd gear — intentional GM limp mode)
  - max line pressure (0% EPC duty)
  - TCC off (enable OFF, PWM 0%)
- **0% EPC duty (max pressure) triggers:**
  - MCU reset / watchdog timeout
  - sensor loss (TPS, VSS)
  - over-temperature
  - any fault condition
- Loss of VSS:
  - inhibit downshifts
  - inhibit TCC
- Over‑temperature:
  - disable TCC
  - raise line pressure
- MCU watchdog enabled at all times

---

## 8) Practical Tuning Advice

- Start with **fixed high pressure**
- Verify correct gear engagement
- Add TPS‑based pressure mapping
- Add shift pressure bump
- Enable TCC last

---

## 9) Intended Use

This document is intended to support:
- Teensy‑based TCM projects
- MegaShift / GPIO‑style controllers
- Manual‑mode or paddle‑shift 4L60‑E builds

Improper control of automatic transmissions can cause damage or injury.  
Proceed carefully and test incrementally.

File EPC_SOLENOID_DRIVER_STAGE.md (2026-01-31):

EPC + Solenoid Driver Stage

4L60-E | Teensy 4.1 | Automotive-safe

1️⃣ Design philosophy (important)

Low-side switching (OEM-correct for GM)

MCU never drives solenoids directly

EPC must survive continuous PWM

Fail-safe bias = MAX pressure

Flyback suppression that won’t kill MOSFETs

Survives load dump, inductive kick, noise

2️⃣ Solenoids to drive
Solenoid	Type	Control
SSA	On/Off	Digital
SSB	On/Off	Digital
TCC	On/Off enable	Digital
TCC PWM	PWM progressive apply	PWM (20-100 Hz)
EPC / PCS	PWM, current-controlled-ish	Critical

EPC current range: **0–1.1 A** (0A = max pressure, ~1.1A = min pressure), continuous PWM.

3️⃣ Recommended topology (one channel)

All solenoids use the same base topology, EPC just needs better thermal handling.

+12V ---- Solenoid ---- Drain MOSFET Source ---- GND
                      |
                      +-- Flyback clamp (TVS)
Gate ← Gate resistor ← Teensy pin
         |
        Gate pulldown

4️⃣ MOSFET selection (do NOT cheap out)
Recommended MOSFET (proven automotive choice)

**STP36NF06L** (ST Microelectronics)

- 60V VDS
- 30A ID (continuous)
- 40mΩ RDS(on) max @ VGS=10V
- Logic-level gate (VGS(th) 1.0–2.5V, 3.3V compatible)
- Low gate charge (13–17nC)
- **AEC-Q101 automotive qualified**
- TO-220 package (hand-solderable)

Good alternatives:

- Infineon BSC010NE2LS5 (SMD)
- IPB044N06L3

⚠️ Avoid random eBay MOSFETs.

5️⃣ Gate drive network (critical for noise immunity)
Gate components (per solenoid)
Component	Value	Purpose
Gate resistor	100 Ω	Limits inrush, reduces ringing
Gate pulldown	100 kΩ	Ensures OFF at reset
MCU pin	3.3V	Teensy compatible

Why this matters

Prevents accidental turn-on during reset

Controls EMI

Improves MOSFET longevity

6️⃣ Flyback protection (THIS IS NOT OPTIONAL)

### For SSA / SSB / TCC (on/off solenoids)

Use **bidirectional TVS** across solenoid:

- Recommended: **5KP36CA** (36V clamp, 5000W peak pulse, axial) or SMBJ36CA (SMD)
- Connection: Drain ─── TVS ─── +12V

This allows:

- fast current decay
- controlled voltage spike
- crisp solenoid release

### For EPC (PWM pressure control)

Use a **diode** (e.g., **1N4001** or 1N4007) across the EPC solenoid:

- Connection: Cathode to +12V, Anode to Drain
- The slower current decay acts as a **low-pass filter** on pressure
- Results in **smoother pressure modulation**

This matches MegaShift recommendations for "greater line pressure control."

Optionally add a small TVS (5KP36CA) in parallel for spike protection.

| Solenoid | Flyback Type | Reason |
|---|---|---|
| SSA | TVS | Fast response for shifts |
| SSB | TVS | Fast response for shifts |
| TCC | TVS | Crisp lockup engagement |
| TCC PWM  | Diode | Smooth progressive apply |
| EPC | Diode (+TVS) | Smooth pressure modulation |

7️⃣ EPC PWM specifics (very important)
PWM frequency

Recommended: 200–300 Hz

Matches GM PCS behavior

Avoids audible noise

Avoids heating the solenoid

Teensy hardware PWM handles this perfectly.

Default EPC behavior (hardware + firmware)

Gate pulldown ensures OFF if MCU dies

Firmware sets **0% duty on fault** (max pressure, project assumption)

Solenoid supply is always present

8️⃣ EPC direction and pressure abstraction

**Hardware behavior (GM 4L60E):**

- Higher EPC duty → more current → exhaust open longer → **lower** line pressure
- Lower EPC duty → less current → exhaust closed more → **higher** line pressure
- 0% duty = max pressure (failsafe)

**Firmware abstraction (recommended):**

Use a **Pressure Command %** scale (0–100%, where 100% = max pressure).
Convert to EPC duty via inversion in one place:

```text
pressure_cmd 100% → EPC duty ~5%  (max pressure)
pressure_cmd 0%   → EPC duty ~60% (min pressure, hard ceiling)
```

**Important:** 60% duty is a hard upper limit — not comfort tuning, but thermal + hydraulic protection. At ~4Ω coil, this limits average current to ~1.1A.

This keeps tuning tables intuitive (higher TPS → higher pressure command).

9️⃣ Current handling & thermal design
EPC MOSFET

Continuous PWM = heat

Mount MOSFET to:

copper pour on PCB or

small aluminum heatsink

On/off solenoids

Lower duty

No heatsink usually needed

10️⃣ Protection on the 12V supply (mandatory)
At the driver board input:

TVS diode: SMBJ58A (load dump protection)

Reverse polarity protection

P-channel MOSFET OR

Schottky diode (less ideal)

Decoupling

100 µF electrolytic near solenoids

0.1 µF ceramic per channel

11️⃣ Full driver channel BOM (per solenoid)
Part	Value
MOSFET	STP36NF06L (TO-220)
Gate resistor	100 Ω
Gate pulldown	100 kΩ
Flyback TVS	5KP36CA (axial)
Decoupling cap	0.1 µF
Bulk cap	100 µF (shared rail)
12️⃣ Wiring summary (Teensy → Driver)
Signal	Teensy	Driver
SSA	Pin 2	Gate via 100Ω
SSB	Pin 3	Gate via 100Ω
TCC	Pin 4	Gate via 100Ω
TCC PWM	Pin 12 (PWM)	Gate via 100Ω
EPC	Pin 5 (PWM)	Gate via 100Ω
GND	GND	Power ground
+12V	Vehicle	Solenoid feed
13️⃣ Fail-safe behavior (designed in)
Failure	Result
MCU reset	SSA/SSB default to 3rd (both OFF — intentional GM limp mode), TCC OFF, TCC PWM 0%, EPC 0% duty
EPC fault	Firmware forces 0% duty (max pressure)
Pi crash	No effect
Sensor loss	MAX pressure, no TCC
Brownout	Gate pulldowns force OFF
14️⃣ What this design deliberately avoids

❌ Relay switching (too slow)

❌ ULN2003 / Darlington arrays (voltage drop, heat)

❌ Flyback diodes only (bad shift quality)

❌ Direct MCU drive (dangerous)

Next steps (pick one)

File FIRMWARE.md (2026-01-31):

# Firmware Design – Teensy 4.1 TCM

This document describes the firmware logic running on the Teensy 4.1.

---

## Firmware Responsibilities

The Teensy is the authoritative transmission controller.

It is responsible for:
- Gear selection from range input
- Solenoid control (SSA / SSB)
- EPC (line pressure) PWM control
- TCC control (on/off enable + PWM progressive apply)
- Downshift protection
- Failsafe handling
- Watchdog monitoring

The firmware runs independently of the Raspberry Pi.

---

## Operating Mode

### Manual Mode Only
- No automatic upshifts or downshifts
- Gear is commanded directly by shifter position

| Shifter | Commanded Gear |
|---|---|
| 1 | 1st |
| 2 | 2nd |
| 3 | 3rd |
| D | 4th |

---

## Core State Machine

### States
- INIT
- IDLE
- HOLD_GEAR
- SHIFTING
- FAILSAFE

### Transitions
- Shifter change → SHIFTING
- Shift complete → HOLD_GEAR
- Sensor fault → FAILSAFE

---

## Shift Execution Logic

1. Detect requested gear change
2. Validate downshift (speed check)
3. Apply EPC shift bump
4. Change SSA / SSB states
5. Hold bump for fixed duration
6. Ramp EPC back to base pressure

---

## EPC (Line Pressure) Control

### Pressure Command Abstraction

Firmware uses a **Pressure Command %** scale internally:

| Pressure Command | Meaning |
|---|---|
| 0% | Minimum line pressure |
| 100% | Maximum line pressure |

This is converted to EPC duty via inversion (GM-style):

```text
Pressure 100% (max) → EPC duty ~5% (near OFF)
Pressure 0% (min)   → EPC duty ~60% (hard ceiling)
```

**Important:** 60% duty is a hard upper limit, not arbitrary. At ~4Ω coil resistance, this limits average current to ~1.1A for thermal and hydraulic protection.

**Why this abstraction?**

- Tuning tables are intuitive (higher load → higher pressure command)
- Inversion happens in one place, not scattered through code
- Matches MegaShift and other controller conventions

### Base Pressure Mapping

| TPS | Pressure Command |
|---|---|
| 0% (closed) | ~30% |
| 25% | ~40% |
| 50% | ~55% |
| WOT | ~70% |

(Values are starting points — tune with a line pressure gauge.)

### Shift Bump

- Temporarily raise pressure command (e.g., +20%)
- Duration: ~200–400 ms (tunable)

### Failsafe

- Invalid TPS / VSS / fault → **100% pressure command** (max pressure, ~0% EPC duty)

---

## Torque Converter Clutch (TCC)

### Enable Conditions
- Gear: 3rd or 4th
- Vehicle speed above threshold
- TPS below threshold
- Brake not applied
- **Delay timer satisfied** (prevents lock/unlock cycling)

### Disable Conditions

- Brake input (immediate unlock)
- Shift in progress
- Over-temperature
- Sensor fault
- Throttle transient (rapid TPS change)

### TCC PWM Progressive Apply

The TCC PWM solenoid modulates converter clutch apply pressure for smooth lockup:

- On lockup request, ramp TCC PWM duty from 0% up over ~500–1000 ms
- TCC enable (on/off) is energised first, then TCC PWM ramps up
- On unlock, TCC PWM drops to 0% immediately, then TCC enable turns off
- PWM frequency: 20–100 Hz (same MOSFET driver topology as EPC, with diode flyback)
- Failsafe: 0% TCC PWM duty = no progressive apply (converter stays unlocked)

### TCC Design Philosophy

Per FuelTech practice: hysteresis and delays matter more than fancy logic. TCC must never fight EPC or gear changes. Conservative, delayed lockup is industry standard.

---

## Safety & Failsafes

- Watchdog timer enabled
- Default output states on reset:
  - SSA OFF, SSB OFF → 3rd gear (intentional GM limp mode)
  - Max EPC pressure (0% duty)
  - TCC unlocked (enable OFF, PWM 0%)
- VSS loss:
  - Lock out downshifts
  - Disable TCC
- Over-temp:
  - Disable TCC
  - Increase EPC pressure

---

## Communication with Raspberry Pi

### Telemetry (Teensy → Pi)
- Current gear
- SSA / SSB state
- EPC duty
- TPS
- VSS
- TCC state
- Transmission temperature

### Commands (Pi → Teensy, optional)
- Mode selection
- Configuration updates

All incoming commands are validated before use.

---

## Development Strategy

1. Fixed EPC, fixed gear control
2. Add VSS + downshift protection
3. Add TPS-based EPC mapping
4. Add TCC logic
5. Add logging + configuration

---

## Repo Structure (Firmware)

The firmware is organized as a PlatformIO project under `firmware/`.

- `firmware/src/` – Implementation modules (state machine, EPC, VSS, TCC)
- `firmware/include/` – Public headers and pin map (`board_config.h`)
- `firmware/config/` – Build/runtime config headers

Build + upload:

```bash
pio run -d firmware
pio run -d firmware -t upload
```

---

## Guiding Principles

- Deterministic behavior
- Conservative pressure bias
- No hidden automation
- Transmission safety above comfort

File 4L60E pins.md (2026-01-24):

Inputs to GPIO
Pin
Function
L	Temperature Sensor Signal
M	Temperature Sensor GND
N	Pressure Switch A (aka. Input1)
R	Pressure Switch B (aka. Input2)
P	Pressure Switch C (aka. Input3)
n/a	2WD/4WD Input (ground for 4WD)
n/a	Vehicle Speed Sensor (VSS) - has its own 2-pin connector

Outputs from GPIO
Pin
Function
Control	Limits
A	Sol A (1-2/3-4) Switched GND (aka. Output1)	On/Off	20-40 Ohms (0.75 Amps Max.)
B	Sol B (2-3) Switched GND (aka. Output2)	On/Off	20-40 Ohms (0.75 Amps Max.)
C	Pressure Control Solenoid High	Power (nominal +12V)	Switched 12V from harness
D	Pressure Control Switched GND	PWM (293Hz)	0 to 60% (3.5 - 4.6 Ohms at 20°C, 1.1 Amps Max.)
E	+12 Volt Power	High (nominal +12V)	Switched 12V from harness
U	Lock-Up Feel Solenoid Switched GND not always used	PWM (32 Hertz)	10-11.5 Ohms at 20°C
S	3-2 Sol Switched GND (aka. Output3)	PWM (50Hz)	9-14 Ohms at 20°C
T	Torque Converter Clutch Solenoid Switched GND	On/Off	20-40 Ohms (1.5 Amps Max.)

# 4L60-E MegaShift Wiring Reference

This reference is based on the MegaShift 4L60E wiring documentation. :contentReference[oaicite:1]{index=1}

## 1) Solenoid Outputs & Control

The 4L60-E uses multiple solenoids, driven by switched grounds or +12V:

| Function | Wiring | Control Type | Notes |
|---|---|---|---|
| Solenoid A (1-2 / 3-4) | Switched GND | On/Off | 20-40Ω, ~0.75A max :contentReference[oaicite:2]{index=2} |
| Solenoid B (2-3) | Switched GND | On/Off | 20-40Ω max :contentReference[oaicite:3]{index=3} |
| 3-2 Solenoid | Switched GND | PWM (~50Hz) | 9-14Ω :contentReference[oaicite:4]{index=4} |
| Pressure Control (PC) | +12V & Switched GND | PWM (~293Hz) | 3.5-4.6Ω, ~1.1A :contentReference[oaicite:5]{index=5} |
| Torque Converter Clutch (TCC) | Switched GND | On/Off or PWM | 20-40Ω, ~1.5A :contentReference[oaicite:6]{index=6} |
| Lock-Up Feel (LUF) | Switched GND | PWM (~32Hz) | Optional in some versions :contentReference[oaicite:7]{index=7} |

Solenoids share a common +12 V feed on pin E (except PC solenoid which has its own +12 V on pin C). :contentReference[oaicite:8]{index=8}

---

## 2) AMPseal Connector Pinout

| AMPseal Pin | Function |
|---|---|
| 1 | +12V Power |
| 2 | VSS (VR1) |
| 3 | Brake Sense |
| 4 | Paddle DOWN |
| 5 | 2WD/4WD Sense |
| 6 | Pressure Switch B |
| 7 | LED2 (GPO2) |
| 8 | LED3 (GPO3) |
| 9 | LED4 (GPO4) |
| 10 | LED1 (GPO1) |
| 12 | Spare Output2 |
| 15 | Paddle UP |
| 23 | Solenoid A |
| 24 | non-CAN MAP/TPS/MAF |
| 25 | Pressure Switch C |
| 26 | Pressure Switch A |
| 27 | Line Pressure Sensor |
| 28 | Vref (+5V) |
| 30 | Temp Sensor |
| 31 | Speedo Output |
| 32 | TCC Solenoid |
| 33 | PC GND PWM |
| 34 | 3-2 Sol PWM |
| 35 | Solenoid B |
| 17,18,19,20 | Grounds |
| 13,16 | CAN H/L |
:contentReference[oaicite:9]{index=9}

---

## 3) Sensor Inputs

- **VSS (Vehicle Speed Sensor)** — typically VR sensor. :contentReference[oaicite:10]{index=10}  
- **Brake Sense** — ground signal when braking. :contentReference[oaicite:11]{index=11}  
- **Pressure Switches A/B/C** — indicate manual valve position via hydraulic switch block. :contentReference[oaicite:12]{index=12}  
- **Temp Sensor** — transmission temperature. :contentReference[oaicite:13]{index=13}  
- **Line Pressure Sensor (optional)** — 0.5-4.5 V transducer. :contentReference[oaicite:14]{index=14}

---

## 4) Pressure Switch “Manual Valve” Table

| Gear | Switch A | Switch B | Switch C |
|---|---|---|---|
| 1st | 0 | 1 | 1 |
| 2nd | 1 | 1 | 1 |
| 3rd | 1 | 1 | 0 |
| 4th | 1 | 0 | 0 |
Park/Neutral/Reverse also have unique states. :contentReference[oaicite:15]{index=15}

---

## 5) Notes on PC Solenoid Behavior

- PWM duty inversely related to throttle load (higher duty = higher pressure). :contentReference[oaicite:16]{index=16}  
- OEM runs ~293 Hz, 0-60% duty range. :contentReference[oaicite:17]{index=17}

---

## 6) Additional Notes

- 4L60E uses a common ground switch-to-engage style for most solenoids. :contentReference[oaicite:18]{index=18}  
- The PC solenoid has its own +12 V feed pin and is switched on the ground side via PWM. :contentReference[oaicite:19]{index=19}  
- You can use this wiring reference with any standalone controller (like a Teensy-based TCM) to map inputs/outputs correctly.

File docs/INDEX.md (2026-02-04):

# Docs Index

This repo has a lot of solid content already; this file is just a fast navigation layer.

## Core docs

- `README.md` — overview + architecture
- `HARDWARE.md` — electrical architecture + IO + safety defaults
- `FIRMWARE.md` — logic/state machine + EPC + TCC + failsafes
- `CONTROLLER_PINOUT.md` — controller pinout (authoritative wiring reference)
- `EPC_SOLENOID_DRIVER_STAGE.md` — driver stage design notes
- `BOM_LIST.md` — BOM
- `TODO.md` — plan

## Resources

- `resources/INDEX.md`
- `resources/4l60e/INDEX.md`

## Search (optional)

- `QMD_SETUP.md` — optional local search workflow (QMD)

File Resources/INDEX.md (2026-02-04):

# Resources Index

This folder is reference material (PDFs, wiring diagrams, connector pinouts, photos, board notes).

## How to use

- If you’re using QMD (or any search tool), it will index **markdown/txt** best.
- For PDFs/images, consider adding **text sidecars** next to the file (same name + `.txt`) for searchability.

## Subfolders

- `4l60e/` — transmission reference docs (manuals/specs/wiring diagrams/pinouts)
- `pi_zero_2w/` — Raspberry Pi Zero 2W reference (pins etc)

See also: `resources/4l60e/INDEX.md`

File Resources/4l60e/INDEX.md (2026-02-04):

# 4L60E Resources Index

Goal: quick map of the reference files in this folder.

## PDFs

- `4l60e English.pdf`
  - Main reference document (contents: specs/procedures/diagrams). Add notes below when you find key pages.

- `4L60E Transmission Specs, Gear Ratios, & History.pdf`
  - General specs/ratios/history reference.

- `wiring_diagram_1.pdf`
- `wiring_diagram_vz_ecu.pdf`
  - Wiring diagrams (useful for signal tracing).

## Images (pinouts / diagrams / photos)

- `case_connector*.png` — case connector pinout references
- `range_selector_switch.png` — range selector switch reference
- `tcc_solenoid_info.png` — TCC solenoid notes
- `info_microsquirt_4l60e_*.png` — MicroSquirt/4L60E wiring notes
- `wiring_diagram_2.png`, `wiring_diagram_3.png`, `wiring_diagram_4.png` — diagram screenshots
- `vz trans left.jpg`, `vz trans right.jpg` — transmission photos

## Suggested “sidecar” text files (for search)

If you start extracting text, keep it alongside the source:

- `wiring_diagram_1.pdf.txt`
- `4l60e English.pdf.txt`
- `case_connector.png.txt` (OCR)

Even rough OCR is better than nothing for retrieval.

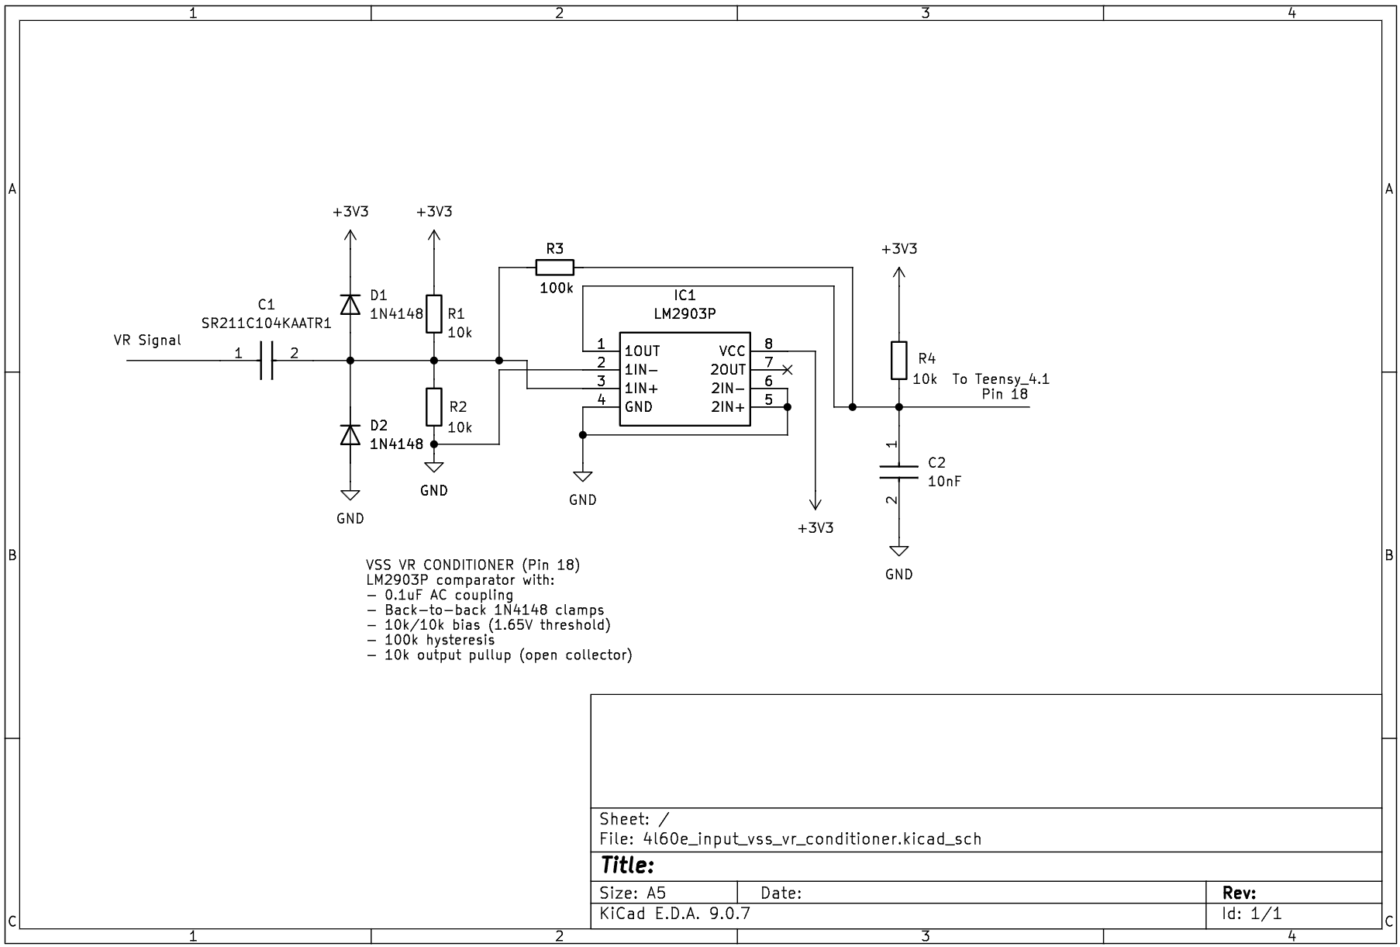
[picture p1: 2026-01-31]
kicad_4l60e/individual_schematics/4l60e_input_vss_vr_conditioner.png

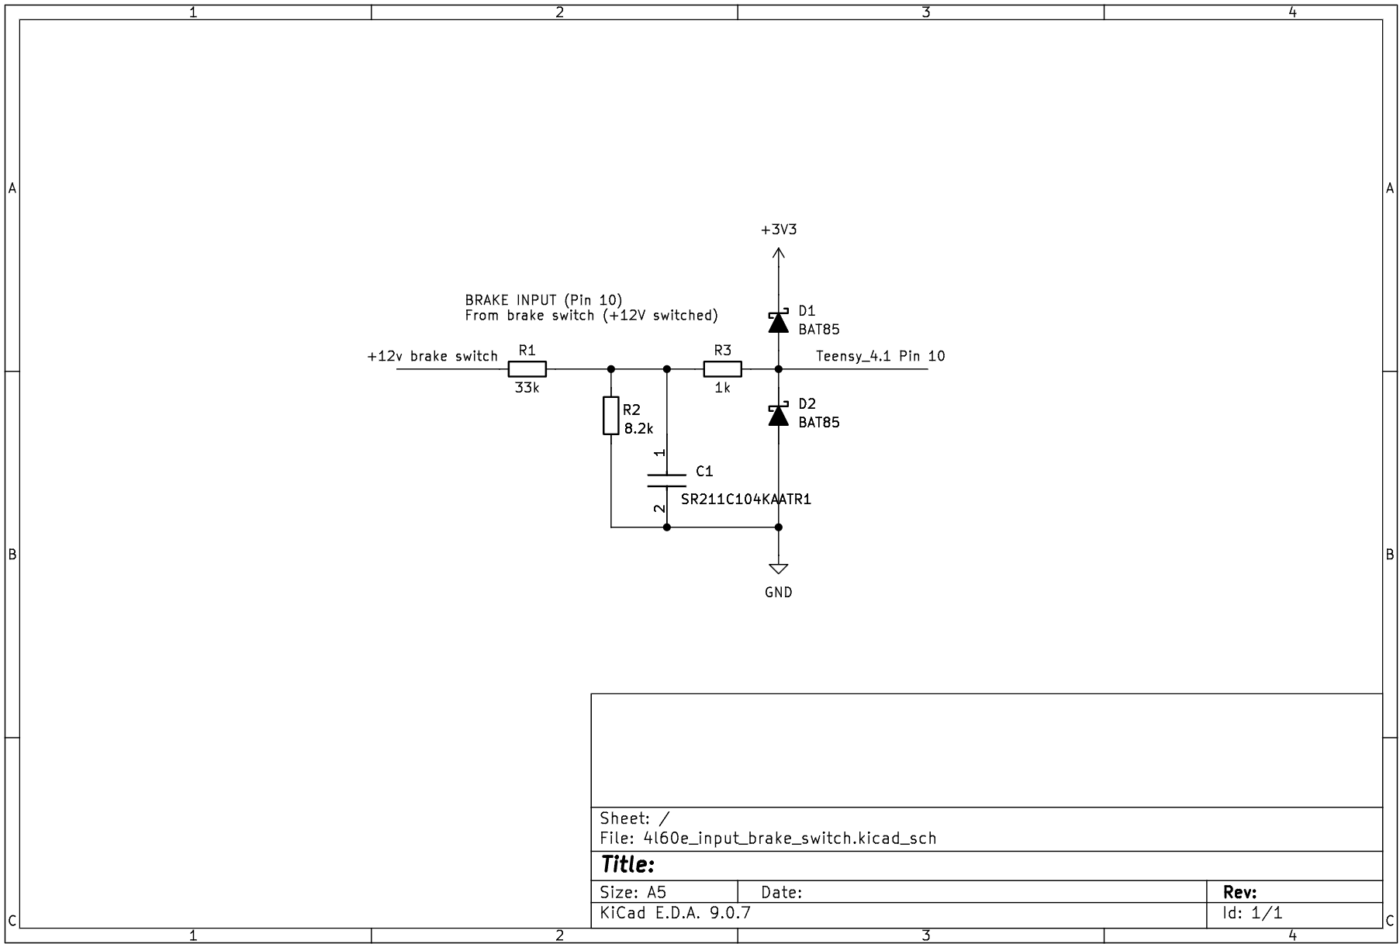
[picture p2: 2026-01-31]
kicad_4l60e/individual_schematics/4l60e_input_brake_switch.png

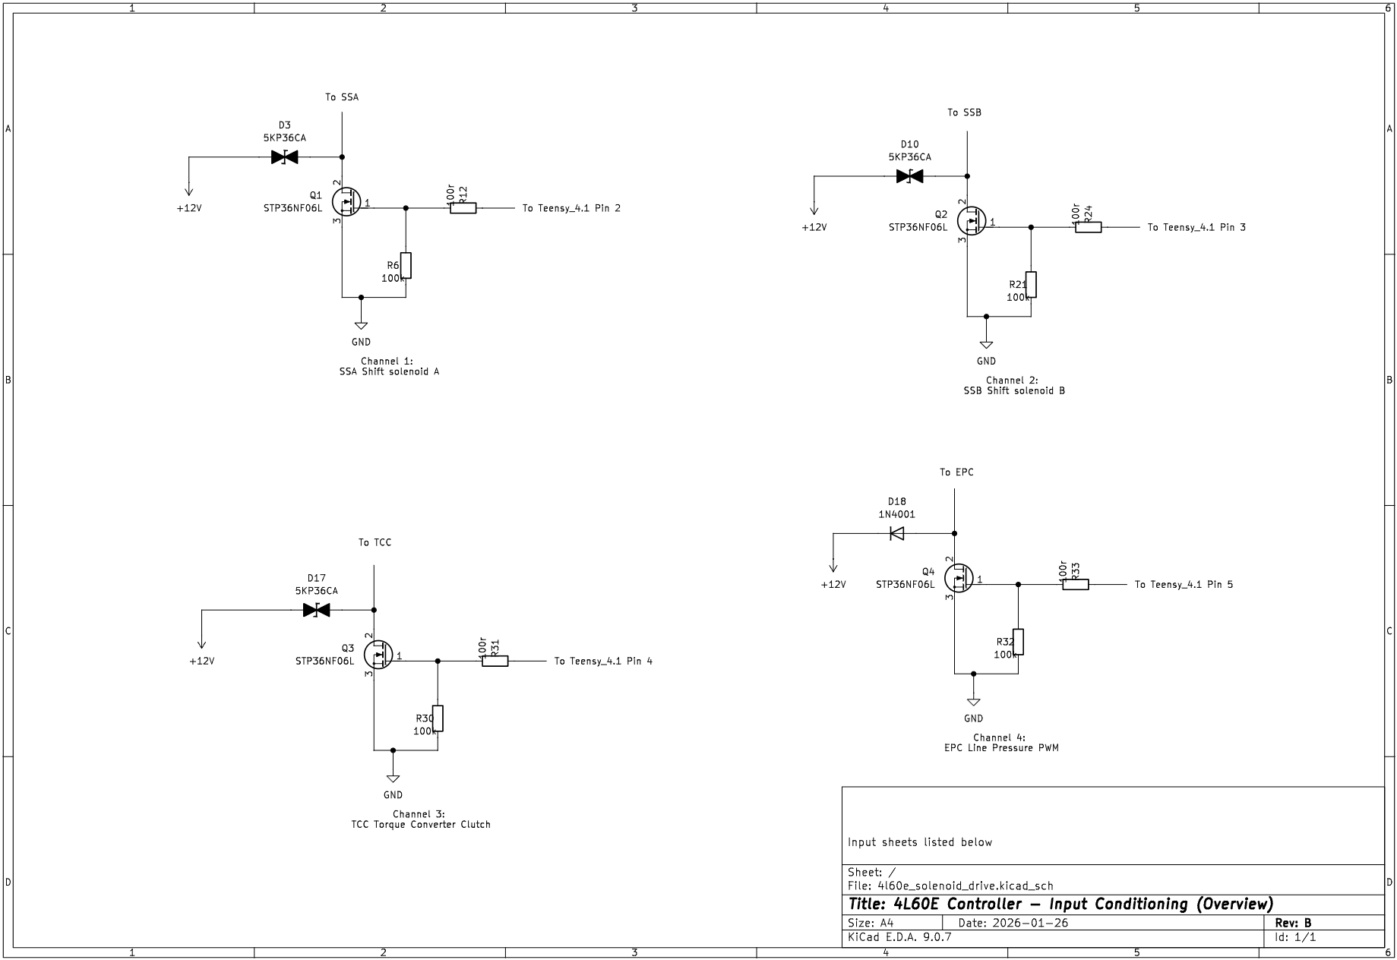
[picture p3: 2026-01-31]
kicad_4l60e/individual_schematics/4l60e_solenoid_drive.png

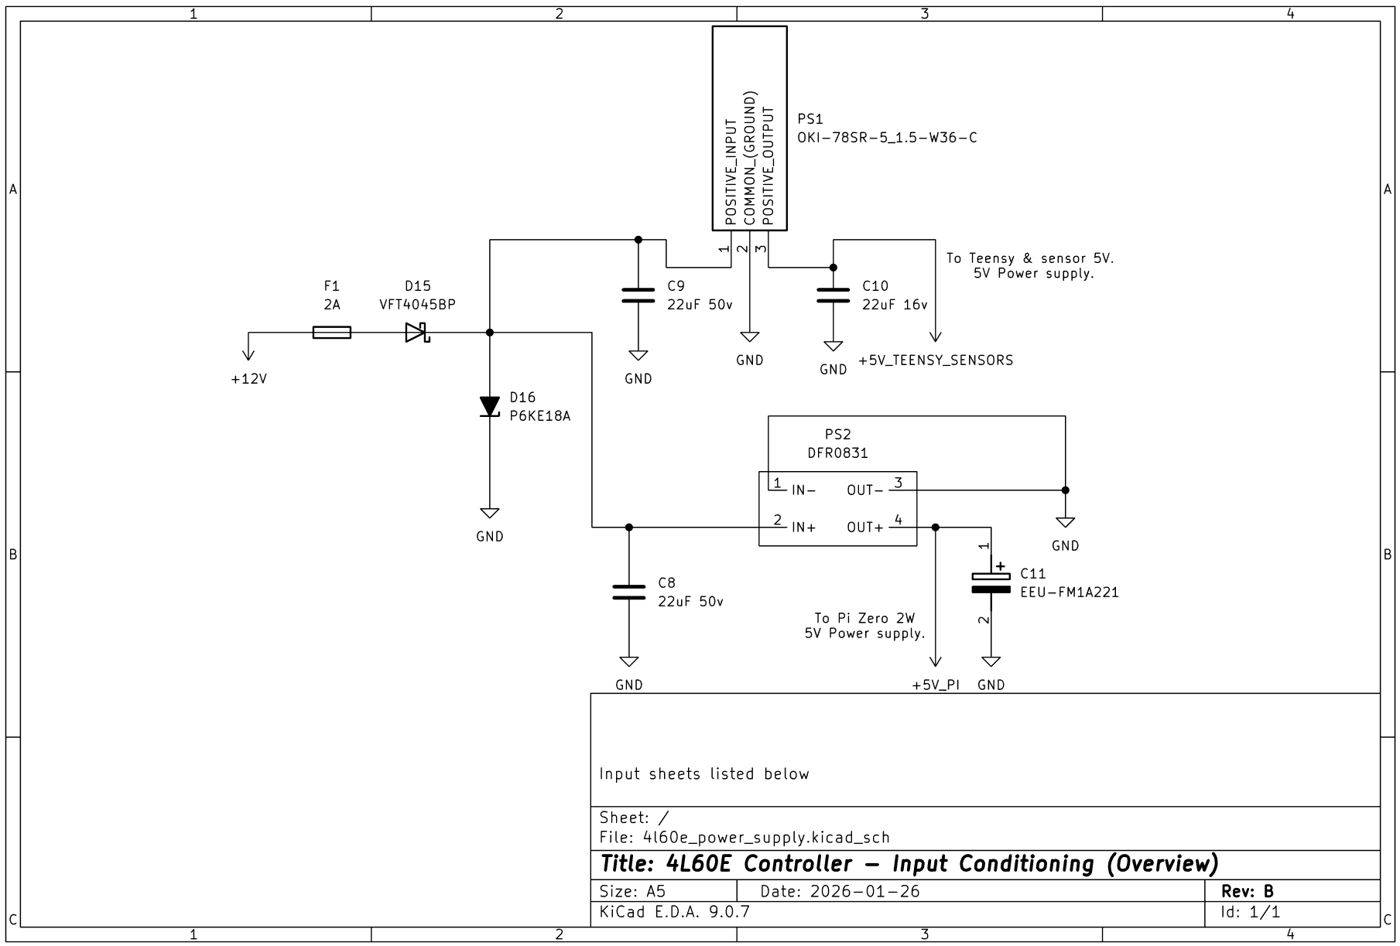
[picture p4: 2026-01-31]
kicad_4l60e/individual_schematics/4l60e_power_supply.png

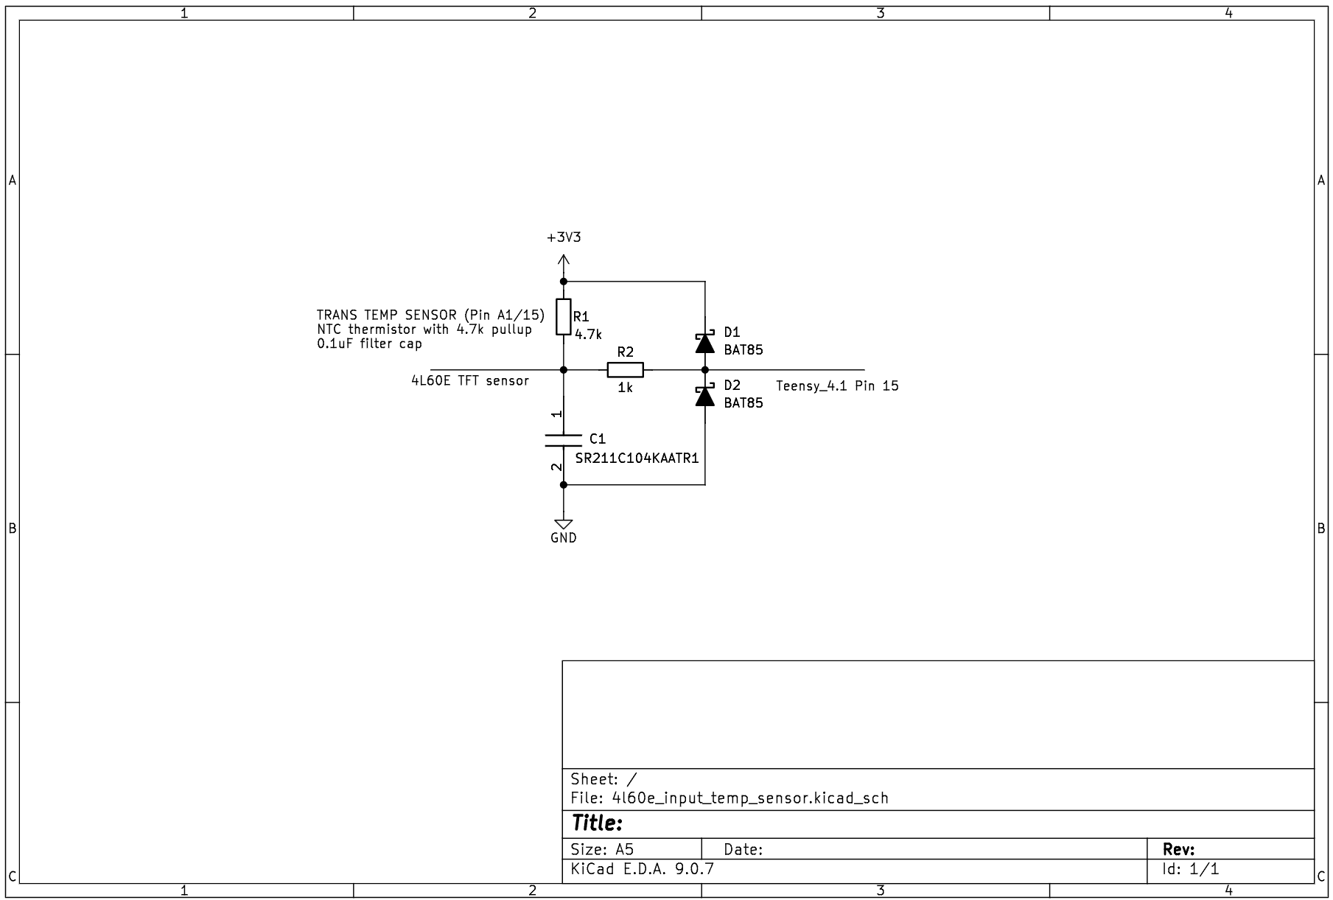
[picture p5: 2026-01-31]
kicad_4l60e/individual_schematics/4l60e_input_temp_sensor.png

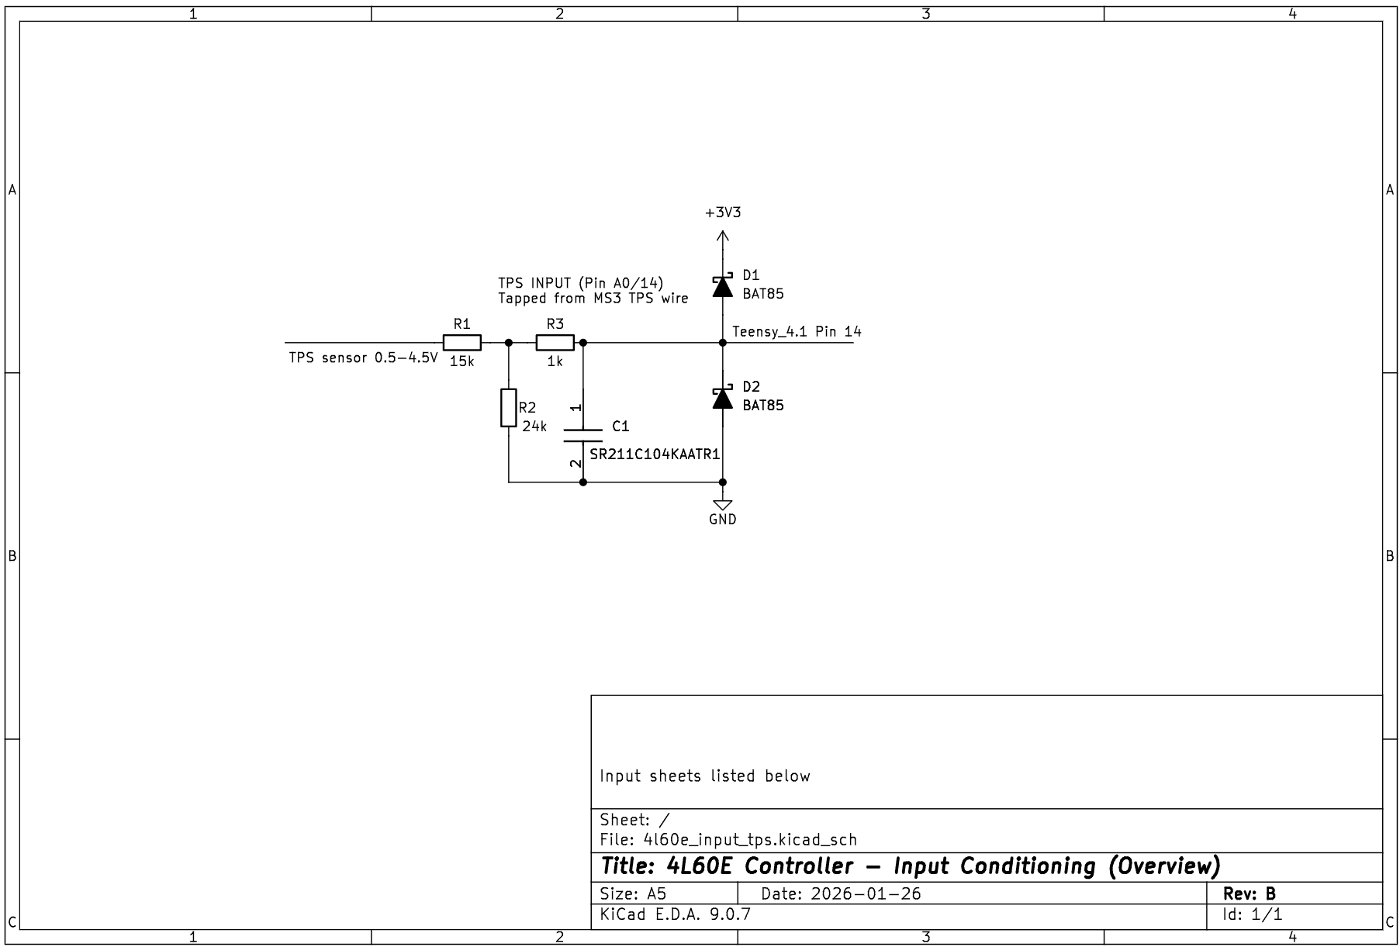
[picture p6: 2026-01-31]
kicad_4l60e/individual_schematics/4l60e_input_tps.png

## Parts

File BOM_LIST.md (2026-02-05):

# 4L60-E Manual Controller -- DIY-Friendly BOM (No Tiny SMD)

This BOM is aimed at **hand-solderable parts** (through-hole, TO-220/TO-247, radial/axial leaded, and plug-in modules).
It covers the core controller plus a **4-channel low-side solenoid driver stage** (SSA, SSB, TCC, EPC).

> Notes:
> - Use **automotive wire**, proper crimp tooling, and fuse protection.
> - Values shown are "known-good starting points" for a 4L60-E manual-mode controller.
> - Where possible, I list **common, easily sourced** example parts; equivalents are fine.

---

## 1) Core compute + comms

| Item | Qty | Example Part | Package | Notes |
|---|---:|---|---|---|
| Real-time controller | 1 | **Teensy 4.1** | Module | Main TCM controller |
| Logging / UI (optional) | 1 | **Raspberry Pi Zero 2 W** | Module | Optional; Teensy must run standalone |
| UART level | 1 | (none) | -- | Teensy<->Pi is **3.3V TTL**; keep wiring short, twisted if possible. 2x CP2102 USB-TTL adapters for bench |
| USB cable (bench) | 1 | USB-A to Micro-B | -- | Firmware upload + bench debug |

---

## 2) Power input + protection (vehicle 12V to clean 5V)

| Item | Qty | Example Part | Package | Notes |
|---|---:|---|---|---|
| Main fuse (solenoids + controller feed) | 1 | **ATO/ATC inline fuse holder** + 15-25A fuse | Inline | Size depends on solenoid wiring + accessories |
| Controller fuse (logic only) | 1 | Inline fuse holder + **2A fast-blow** fuse | Inline | Per OKI-78SR datasheet recommendation |
| Reverse polarity protection | 1 | **VFT4045BP** Schottky rectifier | TO-220 | 45V/40A, 0.41V drop at 5A; blocks reverse polarity |
| Load-dump / surge TVS (12V rail) | 1 | **P6KE18A** | Axial leaded | 15.3V standoff, 18V breakdown; clamps automotive transients to safe levels |
| Bulk capacitor (12V) | 1-2 | 470-1000 uF, 35V, low-ESR | Radial | Place near driver board input |
| Buck input cap (Teensy) | 1 | **22uF ceramic, 50V** (X5R or X7R) | Through-hole | Close to OKI-78SR input pins; low ESR required per datasheet |
| Buck output cap (Teensy) | 1 | **22uF ceramic, 10V** | Through-hole | OKI-78SR output filter; do not exceed 300uF low-ESR |
| Buck input cap (Pi) | 1 | **22uF ceramic, 50V** (X5R or X7R) | Through-hole | Close to DFR0831 input |
| Decoupling caps | 4-10 | 0.1 uF | Through-hole disc | One near each driver channel + logic rail |
| 12V to 5V buck for Teensy | 1 | **OKI-78SR-5/1.5-W36E-C** | SIP module | 7-36V input, 5V/1.5A; drop-in 7805 replacement |
| 12V to 5V buck for Pi | 1 | **DFR0831** | Module | 7-24V input, 5V/4A; separate from Teensy supply |
| EMI input filter (optional) | 1 | 100 uH choke + 100 uF cap | Through-hole | Optional but helps noise |

---

## 3) Solenoid driver stage (4 channels, low-side MOSFET)

### 3.1 MOSFETs (hand-solderable)
| Item | Qty | Example Part | Package | Notes |
|---|---:|---|---|---|
| Low-side MOSFET (SSA) | 1 | **STP36NF06L** | TO-220 | Logic-level, AEC-Q101 automotive qualified |
| Low-side MOSFET (SSB) | 1 | STP36NF06L | TO-220 | 60V, 30A, 40m ohm RDS(on) |
| Low-side MOSFET (TCC) | 1 | STP36NF06L | TO-220 | Low gate charge (13-17nC) for fast switching |
| Low-side MOSFET (EPC/PCS PWM) | 1 | STP36NF06L | TO-220 | EPC runs PWM continuously -- **heatsink recommended** |
| Heatsinks (EPC at minimum) | 1-2 | TO-220 clip-on or bolt-on heatsink | -- | Use thermal pad/grease as needed |
| Insulators (if shared heatsink) | 1 set | TO-220 mica/silicone pads + shoulder washers | -- | Only if multiple MOSFETs share one heatsink |

### 3.2 Gate network + local caps (per channel)
| Item | Qty | Example Part | Package | Notes |
|---|---:|---|---|---|
| Gate resistor | 4 | 100 ohm, 1/4W | Axial leaded | Limits ringing/inrush |
| Gate pulldown | 4 | 100k, 1/4W | Axial leaded | Ensures OFF at reset |
| Local decoupling | 4 | 0.1 uF | Through-hole disc | Near MOSFET + supply rail |

### 3.3 Flyback / clamp (DIY-friendly)

| Item | Qty | Example Part | Package | Notes |
|---|---:|---|---|---|
| Solenoid clamp TVS (SSA) | 1 | **5KP36CA** | Axial leaded | Bidirectional TVS -- 5000W peak pulse power |
| Solenoid clamp TVS (SSB) | 1 | 5KP36CA | Axial leaded | 36V standoff, fast response |
| Solenoid clamp TVS (TCC) | 1 | 5KP36CA | Axial leaded | |
| EPC flyback diode | 1 | **1N4001** (or 1N4007) | Axial leaded | Smoother pressure modulation |
| EPC spike TVS (optional) | 1 | 5KP36CA | Axial leaded | Extra spike protection if needed |

> **Why different flyback for EPC?**
>
> - **SSA/SSB/TCC** use TVS for fast current decay --> crisp solenoid response
> - **EPC** uses diode for slow current decay --> smoother pressure modulation (matches MegaShift recommendation)

---

## 4) Inputs (DIY-friendly conditioning)

| Input | Qty | Example Part | Package | Notes |
|---|---:|---|---|---|
| TPS scaling (0-5V to 0-3.3V) | 1 | **15k/24k** resistor divider + 0.1uF cap | Axial | 5V in = 3.08V out; safe margin for a 5.25V rail |
| Brake input (12V switched) | 1 | **47k/12k** resistor divider + clamp | Axial | 15V worst case = 3.05V out; add series R + Schottky clamps |
| Trans temp pull-up | 1 | **3.3k** resistor | Axial | NTC pullup to 3.3V on A1 (Pin 15) |
| Line pressure scaling (0-4.5V) | 1 | **15k/24k** resistor divider + 0.1uF cap | Axial | 4.5V in = 2.77V out; sensor powered from 5V_TEENSY rail |
| RPM input (0-12V from MS3) | 1 | **47k/12k** resistor divider + Schottky clamps | Axial | Divider: 12V = 2.44V; clamps are backup only |
| Range selector inputs | 4 | **10k** pullups to 3.3V | Axial | Ground-switched; Teensy has built-in Schmitt triggers |
| Pressure switch inputs | 3 | **10k** pullups to 3.3V | Axial | Ground-switched, gear confirmation (A/B/C on Pins 20-22) |
| VSS VR conditioner | 1 | **LM2903N** | DIP-8 | Dual comparator; 1 of 2 units used (see circuit below) |
| VSS bias resistors | 2 | **10k** (to +3.3V and to GND) | Axial | Sets 1.65V bias/threshold at comparator inputs |
| VSS hysteresis resistor | 1 | **100k** | Axial | From output back to (+) input, prevents chatter |
| VSS output pullup | 1 | **10k** (to +3.3V) | Axial | LM2903 is open-collector, needs external pullup |
| VSS coupling cap | 1 | **0.1uF** film/ceramic | Through-hole | AC couples VR signal to comparator |
| VSS output filter cap | 1 | **0.1uF** ceramic | Through-hole | Cleans output edges |
| VSS protection | 2 | **1N4148** (clamp to 3.3V and GND) | Axial | Clamps VR spikes to safe levels |
| Input clamp diodes | 8 | **1N5817/1N5818/1N5819** | Axial | Schottky clamps for TPS, RPM, line pressure, brake (2 per input) |
| Input series resistors | 4 | **1k** | Axial | Series protection for TPS, RPM, line pressure, brake |
| Schmitt trigger buffer (optional) | 1 | **74HC14** | DIP-14 | Not needed if inputs are clean; Teensy has built-in Schmitt |

---

## 5) Connectors, wiring, and enclosure

| Item | Qty | Example Part | Package | Notes |
|---|---:|---|---|---|
| Transmission connector approach | 1 | **4L60E pigtail** (salvage/aftermarket) | -- | Simplest; avoids sourcing the case connector |
| Controller I/O connectors | 2-6 | **Deutsch DT** 2/3/4/6/8/12 pin | -- | Rugged, common, proper seals |
| Fuse/relay box (optional) | 1 | Sealed mini fuse box | -- | Clean power distribution |
| Wire (solenoids) | as needed | 14-16 AWG TXL/GXL | -- | Higher current runs |
| Wire (signals) | as needed | 18-22 AWG TXL/GXL | -- | Sensors, switches, UART |
| Enclosure | 1 | Sealed polycarbonate box (IP65+) | -- | Cable glands or bulkhead connectors |
| Grounding hardware | 1 set | Ring terminals + star washers | -- | Star-ground at enclosure/chassis point |

---

## 6) Optional but highly recommended sensors

| Item | Qty | Example Part | Package | Notes |
|---|---:|---|---|---|
| Transmission temp sensor | 1 | GM-style TFT sensor (OEM compatible) | -- | Great for TCC inhibit + safety |
| Line pressure sensor | 1 | 0.5-4.5V, 0-300 psi transducer | 1/8" NPT | Makes EPC tuning vastly safer/easier |

---

## 7) Assembly notes (practical)

- Put **EPC MOSFET** on the best heatsinking area (or its own heatsink).
- Keep **power ground** (solenoids) and **sensor ground** separated and joined at a single star point.
- Use **fuses**: one for logic (2A), one for solenoids (15-25A).
- Put the **12V load-dump TVS (P6KE18A)** as physically close to the 12V input as possible.
- Place the **Schottky diode (VFT4045BP)** between fuse and TVS for reverse polarity protection.
- If your VSS is Hall (not VR), you can skip the LM2903N and use a simple pullup + Schmitt input approach.
- All 3.3V pullups are sourced from the **Teensy onboard 3.3V regulator** (250mA capacity, total load ~5mA).

### LM2903N VR Conditioner Circuit

```text
VR sensor (+) --+-- 0.1uF --+----------+--- LM2903 IN+ (pin 3)
                |            |          |
              clamp        10k        100k (hysteresis)
              diodes         |          |
                |            +-- 1.65V -+--- LM2903 OUT (pin 1) --+-- to Teensy Pin 18
VR sensor (-) --+------------+-- GND                              |
                                                                [10k] pullup to +3.3V
                            10k                                   |
              +3.3V -------+-------- LM2903 IN- (pin 2) -- 1.65V ref
                           |
                          10k
                           |
                          GND
```

- The 10k/10k divider sets a **1.65V** threshold at IN- (from +3.3V, not 5V)
- VR signal AC-couples through 0.1uF to IN+
- 100k hysteresis resistor prevents output chatter near zero-cross
- 1N4148 diodes clamp VR spikes: one to GND, one to +3.3V
- Output is **0V/3.3V** square wave at VSS frequency (open-collector with 10k pullup to 3.3V)

---

## 8) Quick quantity summary (core build)

**Compute:**
- Teensy 4.1: **1**
- Raspberry Pi Zero 2 W: **1** (optional)

**Power supply:**
- VFT4045BP Schottky (reverse polarity): **1**
- P6KE18A TVS (12V rail transient clamp): **1**
- OKI-78SR-5/1.5-W36E-C (Teensy 5V buck): **1**
- DFR0831 (Pi 5V buck): **1**
- 22uF ceramic 50V (buck input caps): **2**
- 22uF ceramic 10V (buck output cap): **1**
- Inline fuse holders: **2** (2A logic + 15-25A solenoid)

**Solenoid drivers:**
- STP36NF06L (TO-220): **4**
- Gate resistors 100 ohm: **4**
- Gate pulldowns 100k: **4**
- 5KP36CA TVS for SSA/SSB/TCC: **3**
- 1N4001 EPC flyback diode: **1**
- Bulk caps (470-1000uF, 35V): **2-3**

**Input conditioning resistors:**
- 1k resistors: **4** (series protection for TPS, RPM, line pressure, brake)
- 10k resistors: **10** (range x4 + pressure sw x3 + VSS pullup + VSS bias x2)
- 12k resistor: **2** (brake divider, RPM divider - bottom resistor)
- 15k resistors: **2** (TPS, line pressure dividers - top resistor)
- 24k resistors: **2** (TPS, line pressure dividers - bottom resistor)
- 47k resistors: **2** (brake divider, RPM divider - top resistor)
- 3.3k resistor: **1** (temp pullup)
- 100k resistor: **1** (VSS hysteresis)

**Input conditioning other:**
- 0.1uF caps: **11 total** — 3 input filters (TPS, temp, line pressure), 3 VSS (coupling, output, LM2903 decoupling), 5 solenoid driver decoupling (SSA, SSB, TCC, TCC PWM, EPC)
- 1N4148 diodes: **2** (VSS clamp x2)
- 1N5817/1N5818/1N5819 diodes: **8** (TPS, RPM, line pressure, brake clamps)
- LM2903N (VR comparator): **1**

**Connectors:**
- Deutsch DT connectors + pins/seals: **as needed**

**Optional:**
- 74HC14 Schmitt trigger (DIP-14): **1** (only if noisy inputs)

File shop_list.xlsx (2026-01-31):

Description | Name | PROJECT QTY | STORE | SKU | BUY AMOUNT | PRICE | TOTAL | Total Price
Real‑time controller | Teensy 4.1 (Headers) | 1 | core-electronics | DEV-16996 | 1 | $60.65 | $60.65 | 198.826
Logging / UI | Raspberry Pi Zero 2 W (Wireless) with Soldered Male Headers | 1 | core-electronics | CE09937 | 1 | $32.75 | $32.75
UART level | Adafruit CP2102N Friend - USB to Serial Converter | 1 | core-electronics | ADA5335 | 1 | $11.70 | $11.70
UART level | USB to UART Converter (CP2102) | 1 | core-electronics | CE09216 | 1 | $3.30 | $3.30
Low‑side MOSFET STP36NF06L | N-Channel 60 V 30A (Tc) 70W (Tc) Through Hole TO-220 | 4 | DigyKey | 497-7522-5-ND | 4 | $2.83 | $11.32
EPC flyback diode (1N4001) or 1N4007 | DIODE STANDARD 50V 1A DO204AC | 1 | DigyKey | 4878-1N4001CT-ND | 10 | $0.13 | $1.28
TVS diodes SSA/SSB/TCC 5KP36CA | TVS DIODE 36VWM 58.1VC P600 | 3 | DigyKey | 5KP36CALFCT-ND | 3 | 3.75 | $11.25
High-energy 12V TVS diode for load dump P6KE18A | TVS DIODE 15.3VWM 25.2VC DO15 | 1 | DigyKey | P6KE18AFSCT-ND | 1 | $0.57 | $0.57
Comparator VR conditioner | IC COMPARATOR 2 GEN PUR 8DIP | 1 | DigyKey | LM2903NNS/NOPB-ND | 1 | $2.02 | $2.02
12V→5V buck for Pi | DC-DC BUCK CONVERTER 7-24V TO 5V for pi | 1 | DigyKey | 1738-DFR0831-ND | 1 | $7.75 | $7.75
12V→5V buck for Teensy | DC DC CONVERTER 5V 8W for teensy | 1 | DigyKey | 811-2196-5-ND | 1 | $7.86 | $7.86
Capacitor | CAP ALUM 1000UF 20% 50V RADIAL | 3 | DigyKey | P19651CT-ND | 3 | $3.49 | $10.47
Capacitor Small RC filter | CAP CER 0.1UF 100V X7R RADIAL | 12 | DigyKey | 478-11031-1-ND | 12 | $0.40 | $4.84
Capacitor power supply input | 22 µF ±10% 50V Ceramic Capacitor X7R Radial | 2 | DigyKey | 565-KTD500B226K76A0T00CT-ND | 2 | $4.55 | $9.10
Capacitor power supply output | CAP CER 22UF 16V X7R RADIAL | 1 | DigyKey | 445-FK20X7R1C226M-ND | 1 | $1.28 | $1.28
Diodes | DIODE SCHOTTKY 45V 40A ITO220AC | 1 | DigyKey | VFT4045BP-M3/4W-ND | 1 | $3.48 | $3.48
Inductor | FIXED IND 110UH 4A 42 MOHM TH | 1 | DigyKey | 535-13506-ND | 1 | $4.06 | $4.06
Diodes 1N4148 | DIODE STANDARD 100V 200MA DO35 | 1 | DigyKey | 1N4148FS-ND | 10 | $0.07 | $0.65
Schmitt trigger buffer | IC INVERT SCHMITT 6CH 1INP 14DIP | 1 | DigyKey | TC74HC14APF-ND | 1 | $0.43 | $0.43
Resistors | RES 100 KOHM 1% 1/2W AXIAL | 1 | DigyKey | 749-2060-1-ND | 10 | $0.18 | $1.83
Resistors | RES 20 KOHM 1% 1/2W AXIAL | 1 | DigyKey | 749-2072-1-ND | 10 | $0.18 | $1.83
Resistors | RES 1 KOHM 1% 1/2W AXIAL | 1 | DigyKey | 749-2068-1-ND | 10 | $0.18 | $1.83
Resistors | RES 2.21 KOHM 1% 1/2W AXIAL | 1 | DigyKey | 749-2075-1-ND | 10 | $0.18 | $1.83
Resistors | RES 4.7K OHM 1% 0.6W AXIAL | 1 | DigyKey | A105962CT-ND | 10 | $0.13 | $1.26
Resistors | RES 10 KOHM 1% 1/2W AXIAL | 1 | DigyKey | 749-2062-1-ND | 20 | $0.18 | $3.66
Resistors | RES 100 OHM 1% 1/2W AXIAL | 4 | DigyKey | 749-2061-1-ND | 10 | $0.18 | $1.83

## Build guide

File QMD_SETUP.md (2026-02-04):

# QMD setup for this repo (optional)

Purpose: make it easy to *search* the project documentation (markdown/txt) with keyword + semantic + hybrid reranking.

This does **not** require changing your markdown structure.

## 1) Install QMD (Bun)

```bash
bun install -g https://github.com/tobi/qmd
```

## 2) Create a collection for this repo (only md/txt)

From anywhere:

```bash
qmd collection add "C:\\Users\\Sav\\ProgramingProjects\\4l60e_control" --name 4l60e --mask "**/*.{md,txt}"
```

## 3) Add context hints (helps ranking)

```bash
qmd context add qmd://4l60e "4L60-E manual-mode transmission controller project. Teensy 4.1 + Pi Zero 2W logger. Key docs: HARDWARE.md, FIRMWARE.md, CONTROLLER_PINOUT.md, EPC_SOLENOID_DRIVER_STAGE.md."
qmd context add qmd://4l60e/resources "Reference PDFs, wiring diagrams, connector pinouts, photos. Prefer text sidecars when available."
```

## 4) (Optional) Generate embeddings

```bash
qmd embed
```

## 5) Useful queries

```bash
qmd search "EPC"
qmd search "failsafe"
qmd query "what is the EPC duty/pressure convention and what are the hard limits"
qmd query "downshift protection rules"
qmd query "TCC enable conditions and unlock sequence"
```

## 6) If you want PDFs/images searchable

QMD is best with text. For the PDFs/images under `resources/`, generate **text sidecars** and keep them next to the source files (same basename, `.txt`).

This repo includes scripts under `tools/text-extract/` you can use if you install the required utilities.

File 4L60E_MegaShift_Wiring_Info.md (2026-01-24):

# 4L60-E MegaShift Wiring & Pinout Reference

This document is derived from the MegaShift 4L60-E wiring documentation:
https://www.msgpio.com/manuals/mshift/wiring.html

It consolidates all wiring, pinout, and signal information relevant to building
a standalone transmission controller (e.g. Teensy-based TCM).

---

## 1) Solenoid Outputs

All solenoids are **low-side (ground-switched)** unless noted.

| Solenoid | Function | Control | Resistance | Notes |
|---|---|---|---|---|
| Shift Solenoid A (SSA) | 1–2 / 3–4 shifts | On/Off | 20–40 Ω | Low-side switched |
| Shift Solenoid B (SSB) | 2–3 shifts | On/Off | 20–40 Ω | Low-side switched |
| EPC / PCS | Line pressure | PWM | 3.5–4.6 Ω | Separate +12V feed |
| TCC | Converter lockup | On/Off or PWM | 20–40 Ω | Low-side switched |
| 3–2 Solenoid | Coast downshift | PWM | 9–14 Ω | Optional use |
| LUF (if fitted) | Lockup feel | PWM | ~10–15 Ω | Some variants only |

---

## 2) Solenoid Power Feeds

- **Common +12V feed** for SSA, SSB, TCC, 3–2, LUF
- **Dedicated +12V feed** for EPC solenoid
- All solenoids are activated by **grounding the control pin**

---

## 3) AMPseal Connector Pinout (MegaShift Reference)

| Pin | Function |
|----|---|
| 1 | +12V Power |
| 2 | VSS (VR+) |
| 3 | Brake Switch |
| 4 | Paddle Down |
| 5 | 2WD/4WD Sense |
| 6 | Pressure Switch B |
| 7 | LED2 / GPO2 |
| 8 | LED3 / GPO3 |
| 9 | LED4 / GPO4 |
| 10 | LED1 / GPO1 |
| 12 | Spare Output 2 |
| 13 | CAN H |
| 15 | Paddle Up |
| 16 | CAN L |
| 17 | Ground |
| 18 | Ground |
| 19 | Ground |
| 20 | Ground |
| 23 | Shift Solenoid A |
| 24 | MAP / TPS / MAF (non-CAN) |
| 25 | Pressure Switch C |
| 26 | Pressure Switch A |
| 27 | Line Pressure Sensor |
| 28 | +5V Reference |
| 30 | Transmission Temp Sensor |
| 31 | Speedometer Output |
| 32 | TCC Solenoid |
| 33 | EPC PWM Ground |
| 34 | 3–2 Solenoid |
| 35 | Shift Solenoid B |

---

## 4) Sensor Inputs

### Vehicle Speed Sensor (VSS)
- Typically **2-wire VR sensor**
- Requires conditioning (zero-cross or comparator)
- Frequency proportional to output shaft speed

### Brake Switch
- Active when braking
- Used to unlock TCC immediately

### Transmission Temperature
- GM NTC thermistor
- Used for TCC inhibit and over-temp protection

### Line Pressure Sensor (optional)
- 0.5–4.5V transducer
- Requires +5V reference

---

## 5) Pressure Switch Manifold (Manual Valve)

| Gear | Switch A | Switch B | Switch C |
|----|----|----|----|
| 1st | 0 | 1 | 1 |
| 2nd | 1 | 1 | 1 |
| 3rd | 1 | 1 | 0 |
| 4th | 1 | 0 | 0 |
| Reverse | 0 | 0 | 1 |
| Park / Neutral | 0 | 0 | 0 |

Used for diagnostics and sanity checking.

---

## 6) EPC Control Notes

- PWM frequency ≈ **293 Hz** (OEM)
- Higher duty = **lower** line pressure (exhaust-bleed solenoid)
- 0% duty = max pressure (failsafe)
- Must default to **high pressure on fault** (0% duty)

---

## 7) Standalone Controller Notes

- All solenoids are ground-switched
- Use external drivers (MOSFETs)
- Separate solenoid ground and sensor ground
- Star-ground at controller enclosure

---

## 8) Intended Use

This document is intended as a **technical wiring reference**
for standalone controllers such as:
- Teensy-based TCMs
- MegaShift / GPIO controllers
- Manual-mode or paddle-shift 4L60-E builds

Always test incrementally.

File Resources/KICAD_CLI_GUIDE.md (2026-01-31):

# KiCad CLI Guide (AI-Optimized)

This is a condensed, task-focused guide for using KiCad 9.0 CLI (`kicad-cli`) in this repo.
It assumes Windows and KiCad installed at `C:\Program Files\KiCad\9.0\bin`.

## 1) Always use the full path

```powershell
$cli = 'C:\Program Files\KiCad\9.0\bin\kicad-cli.exe'
& $cli --help
```

## 2) Mental model

`kicad-cli` has top-level subcommands:
- `fp` (footprints)
- `jobset`
- `pcb`
- `sch` (schematics)
- `sym` (symbols)
- `version`

Each subcommand has its own `--help` and nested subcommands.

```powershell
& $cli sch --help
& $cli sch export pdf --help
```

## 3) Schematic tasks (most used)

### 3.1 ERC (Electrical Rules Check)

```powershell
& $cli sch erc --output kicad_4l60e\cli_out\inputs_erc.rpt kicad_4l60e\kicad_4l60e.kicad_sch
```

Options you will likely use:
- `--format report|json`
- `--severity-error|--severity-warning|--severity-all`
- `--exit-code-violations` (exit 5 if any violations)

### 3.2 Export schematic to PDF

```powershell
& $cli sch export pdf --output kicad_4l60e\cli_out\inputs.pdf kicad_4l60e\kicad_4l60e.kicad_sch
```

Useful flags:
- `--black-and-white`
- `--exclude-drawing-sheet`
- `--no-background-color`
- `--pages 1,2` (if multi-page)

### 3.3 Export schematic to SVG (per-sheet)

```powershell
& $cli sch export svg --output kicad_4l60e\cli_out kicad_4l60e\kicad_4l60e.kicad_sch
```

### 3.4 Export netlist

```powershell
& $cli sch export netlist --format kicadsexpr --output kicad_4l60e\cli_out\inputs.net kicad_4l60e\kicad_4l60e.kicad_sch
```

### 3.5 Export BOM (from symbol fields table)

```powershell
& $cli sch export bom --output kicad_4l60e\cli_out\inputs_bom.csv kicad_4l60e\kicad_4l60e.kicad_sch
```

Common controls:
- `--fields Reference,Value,Footprint,${QUANTITY},${DNP}`
- `--labels Refs,Value,Footprint,Qty,DNP`
- `--exclude-dnp`

## 4) PCB tasks (export outputs)

### 4.1 Gerbers

```powershell
& $cli pcb export gerbers --output kicad_4l60e\cli_out kicad_4l60e\kicad_4l60e.kicad_pcb
```

### 4.2 Drill files

```powershell
& $cli pcb export drill --output kicad_4l60e\cli_out kicad_4l60e\kicad_4l60e.kicad_pcb
```

### 4.3 STEP / SVG / PDF

```powershell
& $cli pcb export step --output kicad_4l60e\cli_out\board.step kicad_4l60e\kicad_4l60e.kicad_pcb
& $cli pcb export svg --output kicad_4l60e\cli_out kicad_4l60e\kicad_4l60e.kicad_pcb
& $cli pcb export pdf --output kicad_4l60e\cli_out\board.pdf kicad_4l60e\kicad_4l60e.kicad_pcb
```

## 5) Variables, themes, and drawing sheets

- Override project variables:

```powershell
& $cli sch export pdf -D PROJECT_REV=A -D AUTHOR=Sav --output out.pdf in.kicad_sch
```

- Override drawing sheet:

```powershell
& $cli sch export pdf --drawing-sheet C:\path\to\sheet.kicad_wks --output out.pdf in.kicad_sch
```

- Export with a specific theme:

```powershell
& $cli sch export pdf --theme KiCad Default --output out.pdf in.kicad_sch
```

## 6) AI usage pattern (recommended)

1) Always run `--help` for the specific subcommand you are about to use.
2) Prefer explicit `--output` paths.
3) Put generated outputs under `kicad_4l60e\cli_out` so they are easy to clean up.
4) Capture ERC output and fail if violations are unexpected.

## 7) Automation snippet (PowerShell batch exports)

```powershell
$cli = 'C:\Program Files\KiCad\9.0\bin\kicad-cli.exe'
$sch = 'kicad_4l60e\kicad_4l60e.kicad_sch'
$out = 'kicad_4l60e\cli_out'
New-Item -ItemType Directory -Force -Path $out | Out-Null

& $cli sch erc --exit-code-violations --output (Join-Path $out 'erc.rpt') $sch
& $cli sch export pdf --output (Join-Path $out 'schematic.pdf') $sch
& $cli sch export bom --output (Join-Path $out 'bom.csv') $sch
& $cli sch export netlist --format kicadsexpr --output (Join-Path $out 'netlist.net') $sch
```

## 7) Verified in this repo

These were executed successfully:

```powershell
& 'C:\Program Files\KiCad\9.0\bin\kicad-cli.exe' sch export pdf --output kicad_4l60e\cli_out\inputs.pdf kicad_4l60e\kicad_4l60e.kicad_sch
& 'C:\Program Files\KiCad\9.0\bin\kicad-cli.exe' sch erc --output kicad_4l60e\cli_out\inputs_erc.rpt kicad_4l60e\kicad_4l60e.kicad_sch
```

Outputs exist in `kicad_4l60e\cli_out`.

## 8) Troubleshooting

- If `kicad-cli` is not found, use the full path shown above.
- If PDF/SVG exports are blank, try `--no-background-color` or specify a theme.
- If ERC fails, add `--exit-code-violations` to detect errors in automation.

## 9) Local issues encountered (knowledge base)

- `kicad-cli` was not on `PATH` in this environment; fixed by calling `C:\Program Files\KiCad\9.0\bin\kicad-cli.exe` directly.
- Export outputs were easiest to manage by routing them into `kicad_4l60e\cli_out`.
- In PowerShell, use single quotes around paths with spaces (e.g. `$cli = 'C:\Program Files\KiCad\9.0\bin\kicad-cli.exe'`) to avoid command parsing errors.
- A hand-authored hierarchical overview schematic failed to load in `kicad-cli`; exported each input sheet individually and used a standalone overview schematic with a text index instead.

## 10) AI-generated schematic issues

### Problem: Wire routing doesn't match symbol pin positions

When programmatically generating `.kicad_sch` files, wire endpoints must exactly match symbol pin connection points. KiCad symbols have pins at specific offsets from their origin:

**Symbol pin positions (from KiCad standard libraries):**

| Symbol | Pin | Local Position | Direction |
|---|-----|---|---|
| `Connector_Generic:Conn_01x02` | 1 | (-5.08, 0) | 0° (right) |
| `Connector_Generic:Conn_01x02` | 2 | (-5.08, -2.54) | 0° (right) |
| `Device:R` | 1 | (0, 3.81) | 270° (down) |
| `Device:R` | 2 | (0, -3.81) | 90° (up) |
| `Device:C` | 1 | (0, 2.54) | 270° (down) |
| `Device:C` | 2 | (0, -2.54) | 90° (up) |

**Calculating absolute pin position:**
```
absolute_pin = symbol_position + rotate(local_pin_position, symbol_rotation)
```

**Example:** Resistor R1 at (38.1, 38.1) rotated 90° CCW:
- Pin 1 local: (0, 3.81) → rotated 90° CCW → (-3.81, 0) → absolute: (34.29, 38.1)
- Pin 2 local: (0, -3.81) → rotated 90° CCW → (3.81, 0) → absolute: (41.91, 38.1)

### Problem: Empty `lib_symbols` section

KiCad schematics require symbol definitions in the `lib_symbols` section. If `lib_symbols` is empty:
- Symbols display as squares with "?" marks
- **ERC will report pin connection errors** even with correct wire routing
- CLI export (PDF/SVG) still works (resolves from system libraries)

### Fix: Embed full symbol definitions

The working solution is to embed complete symbol definitions from KiCad's standard libraries into the `lib_symbols` section. Each symbol needs:
- Property definitions (Reference, Value, Footprint, Datasheet, Description)
- Drawing primitives (rectangles, polylines, etc.)
- Pin definitions with positions and types

**Example structure:**
```
(lib_symbols
    (symbol "Device:R"
        (pin_numbers (hide yes))
        (pin_names (offset 0))
        (property "Reference" "R" ...)
        (property "Value" "R" ...)
        (symbol "R_0_1"
            (rectangle (start -1.016 -2.54) (end 1.016 2.54) ...)
        )
        (symbol "R_1_1"
            (pin passive line (at 0 3.81 270) (length 1.27) (number "1" ...))
            (pin passive line (at 0 -3.81 90) (length 1.27) (number "2" ...))
        )
    )
)
```

Symbol definitions can be extracted from:
```
C:\Program Files\KiCad\9.0\share\kicad\symbols\Device.kicad_sym
C:\Program Files\KiCad\9.0\share\kicad\symbols\Connector_Generic.kicad_sym
C:\Program Files\KiCad\9.0\share\kicad\symbols\power.kicad_sym
```

### Pin instance UUIDs

Each symbol instance needs `(pin "N" (uuid "..."))` entries for each pin. These are required for ERC to track connections.

### Expected ERC warnings for standalone sheets

When testing individual schematic sheets, expect these warnings:
- `power_pin_not_driven`: GND symbols have no power source (resolved when integrated)
- `global_label_dangling`: Labels connect to other sheets
- `lib_symbol_mismatch`: Embedded symbols may differ slightly from library versions

### Looking up symbol definitions

Symbol libraries are located at:
```
C:\Program Files\KiCad\9.0\share\kicad\symbols\
```

To find a symbol's pin positions:
```powershell
grep -A 100 'symbol "R"' "C:\Program Files\KiCad\9.0\share\kicad\symbols\Device.kicad_sym"
```

Look for `(pin ... (at X Y angle) ...)` entries to find connection points.

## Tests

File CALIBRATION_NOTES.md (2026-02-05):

# Calibration & Configuration Data

This file tracks **vehicle-specific** and **transmission-specific** calibration data that must be measured/verified before firmware tuning.

---

## 1) Transmission Temperature Sensor

**Status:** ✅ OEM SENSOR DATA CONFIRMED (2026-02-06)

### Original GM 4L60-E Sensor (NTC Thermistor)

**Confirmed Resistance Values (from GM eSI):**

| Temperature | Resistance (Ω) | Notes |
|---|---|---|
| 68°F (20°C) | 3088 - 3942 | Room temp / cold start |
| 212°F (100°C) | 159 - 198 | Boiling point / hot operation |

**Typical operating values:**
- Cold trans (~70°F / 21°C): ~3500 - 4000 Ω
- Normal operating (~190°F / 88°C): ~200 - 250 Ω
- Hot (~230°F / 110°C): ~120 - 150 Ω
- Over-temp (>250°F / 121°C): <100 Ω

**Sensor type:** NTC (Negative Temperature Coefficient) — resistance **decreases** as temperature **increases**

**Connector:** Pins L & M on transmission case 20-pin connector

---

### Your Circuit:
- 3.3kΩ pullup to 3.3V (on Teensy Pin A1)
- NTC thermistor to ground
- Voltage divider: V_out = 3.3V × (R_NTC / (R_NTC + 3300Ω))

**Calculated ADC Voltages:**

| Temp (°F) | Temp (°C) | R_NTC (Ω) | V_ADC (calculated) | ADC 10-bit (0-1023) |
|---|---|---|---|---|
| 68 | 20 | 3500 | 1.70V | ~523 |
| 140 | 60 | 850 | 0.67V | ~206 |
| 190 | 88 | 225 | 0.21V | ~65 |
| 212 | 100 | 178 | 0.17V | ~52 |
| 230 | 110 | 135 | 0.13V | ~40 |

**Note:** With a 3.3kΩ pullup, the voltage drops quickly at higher temps (lower resistance).
This gives you good resolution in the critical 180-230°F range.

---

### Firmware Implementation (Lookup Table Recommended):

```cpp
// Lookup table for GM 4L60-E temp sensor with 3.3kΩ pullup
// ADC value (10-bit) → Temperature (°C)
const uint16_t temp_adc_table[] = {
    523,  // 20°C (68°F) - room temp
    400,  // 30°C (86°F)
    280,  // 40°C (104°F)
    206,  // 60°C (140°F)
    150,  // 70°C (158°F)
    100,  // 80°C (176°F)
    65,   // 88°C (190°F) - normal operating
    52,   // 100°C (212°F)
    40    // 110°C (230°F) - hot
};

const int8_t temp_celsius_table[] = {
    20, 30, 40, 60, 70, 80, 88, 100, 110
};

// Linear interpolation between points
int8_t GetTransTemp(uint16_t adc_value) {
    // (implementation left as exercise)
}
```

**Over-temp thresholds:**
- **130°C (266°F):** Disable TCC, increase line pressure
- **135°C (275°F):** Fault condition, force max pressure, hold current gear

---

### TODO:
- [ ] Bench test: measure actual ADC values at room temp (should be ~520)
- [ ] Verify ADC values match lookup table during first warm-up
- [ ] Fine-tune lookup table if needed based on real measurements
- [ ] Implement over-temp protection in firmware

---

## 2) Pressure Switch Truth Table

**Status:** ✅ OEM TABLE CONFIRMED (2026-02-06)

### Confirmed (GM 4L60-E Standard - MegaShift Documentation):

**Shifter Position → Switch States:**

| Gear Lever Position | Switch A | Switch B | Switch C | Notes |
|---|---|---|---|---|
| Park / Neutral | HIGH | LOW | HIGH | Cannot distinguish P from N |
| Reverse | LOW | LOW | HIGH | Unique pattern |
| 1st (D1) | LOW | HIGH | HIGH | Unique pattern |
| 2nd (D2) | HIGH | HIGH | HIGH | All switches closed |
| 3rd (D3) | HIGH | HIGH | LOW | Unique pattern |
| 4th (D4 / Drive) | HIGH | LOW | LOW | Unique pattern |

**Source:** MegaShift 4L60-E documentation (msgpio.com/manuals/mshift/operation.html)

---

### Hardware Implementation (YOUR CIRCUIT):

Pressure switches are **ground-switched** (normally open, close when hydraulic pressure present):
- Each switch has a **10kΩ pullup to 3.3V** on the controller
- Switch OPEN (no pressure) → MCU reads **HIGH** (3.3V)
- Switch CLOSED (pressure present) → MCU reads **LOW** (0V, pulled to GND)

**Connector Pins:**
- Teensy Pin 20 → Pressure Switch A
- Teensy Pin 21 → Pressure Switch B
- Teensy Pin 22 → Pressure Switch C
- Common GND at transmission case connector

---

### Important Notes:

1. **Manual Valve Position, NOT Actual Gear:**
   - These switches tell you where the **shifter** is, not what gear the transmission is actually in
   - Example: Shifter in "D" (4th position) → switches read HIGH / LOW / LOW
   - But transmission could still be in 1st, 2nd, or 3rd due to solenoid control

2. **Cannot Distinguish Park from Neutral:**
   - Both read: HIGH / LOW / HIGH
   - This is normal for 4L60-E (no hydraulic pressure in either position)
   - Use separate Park/Neutral switch if needed (typically on column shifter)

3. **Use for Gear Confirmation:**
   - Compare commanded gear (solenoid states) with pressure switch readings
   - If mismatch persists for >2 seconds → shift fault, trigger failsafe
   - Example: Commanded 2nd gear (SSA OFF, SSB ON) but switches read 3rd pattern → stuck shift

4. **Diagnostic Codes:**
   - If switches never change → broken wiring or bad manifold
   - If impossible pattern appears (e.g., all LOW) → wiring short

---

### Firmware Implementation:

```cpp
// Read pressure switches (active LOW, inverted logic)
bool sw_a = digitalRead(hw::kPinPressureSwitchA);
bool sw_b = digitalRead(hw::kPinPressureSwitchB);
bool sw_c = digitalRead(hw::kPinPressureSwitchC);

// Decode manual valve position
enum class ManualPosition {
    PARK_NEUTRAL,  // HIGH, LOW, HIGH (cannot distinguish)
    REVERSE,       // LOW, LOW, HIGH
    FIRST,         // LOW, HIGH, HIGH
    SECOND,        // HIGH, HIGH, HIGH
    THIRD,         // HIGH, HIGH, LOW
    FOURTH,        // HIGH, LOW, LOW
    UNKNOWN        // Invalid pattern
};

ManualPosition GetManualPosition(bool a, bool b, bool c) {
    if (a == HIGH && b == LOW && c == HIGH) return ManualPosition::PARK_NEUTRAL;
    if (a == LOW && b == LOW && c == HIGH) return ManualPosition::REVERSE;
    if (a == LOW && b == HIGH && c == HIGH) return ManualPosition::FIRST;
    if (a == HIGH && b == HIGH && c == HIGH) return ManualPosition::SECOND;
    if (a == HIGH && b == HIGH && c == LOW) return ManualPosition::THIRD;
    if (a == HIGH && b == LOW && c == LOW) return ManualPosition::FOURTH;
    return ManualPosition::UNKNOWN;
}
```

---

### Verification Procedure (Still Recommended):

Even though this is the OEM standard, **test on YOUR transmission** to confirm:

1. Connect controller to transmission (engine OFF, key ON)
2. Manually move shifter through all positions: P → R → N → D → 3 → 2 → 1
3. Read pressure switch states via Serial monitor
4. Compare to table above
5. If all match → you're good to go
6. If mismatch → document your actual table (could be non-standard valve body)

### TODO:
- [ ] Bench test pressure switches with multimeter (shifter in each position)
- [ ] Verify truth table matches OEM standard
- [ ] Implement gear confirmation logic in firmware (Phase 2)
- [ ] Test diagnostic detection (stuck switches, impossible patterns)

---

## 3) Brake Switch Configuration

**Status:** ✅ VERIFIED (2026-02-06)

### Confirmed Configuration:
- Brake switch is **+12V-switched** (voltage-switched)
- One terminal: switched +12V from fuse box
- Other terminal: to controller (originally went to OEM TCM)
- When brake pressed: switch closes, +12V applied to controller input

### Hardware Design (CORRECT AS-IS):
- 47kΩ / 12kΩ voltage divider scales +12V down to ~2.4V at MCU pin
- 1kΩ series resistor + dual Schottky clamps protect MCU pin
- Brake NOT pressed: MCU pin reads LOW (~0V)
- Brake pressed: MCU pin reads HIGH (~2.4V)

### Firmware Logic:
```cpp
bool brake_pressed = digitalRead(hw::kPinBrake);
// HIGH = brake pressed, LOW = brake not pressed
```

### No Changes Required
Current schematic and firmware logic are correct for this vehicle.

---

## 4) Line Pressure Sensor Calibration (Optional)

**Status:** NOT INSTALLED YET (Optional sensor)

If you install a line pressure sensor (0.5-4.5V, 0-300 psi):

### Circuit:
- Sensor powered from 5V_TEENSY rail (Pin 1 = +5V, Pin 3 = GND)
- Signal (Pin 2) through 15kΩ / 24kΩ divider → 4.5V becomes 2.77V at ADC
- ADC read on Teensy Pin A2

### Calibration Procedure:
1. Install mechanical pressure gauge on transmission (test port)
2. Start engine, transmission in Park
3. Record:
   - Idle pressure (psi) vs ADC value
   - Increased throttle pressure vs ADC values
4. Generate lookup table or linear equation:
   ```cpp
   float psi = (adc_value - zero_offset) * scale_factor;
   ```

### Uses:
- EPC tuning (verify actual pressure vs commanded)
- Failsafe verification (confirm max pressure on fault)
- Shift quality tuning (shift bump magnitude)

### TODO:
- [ ] Install line pressure sensor (1/8" NPT tap on case)
- [ ] Install mechanical gauge for calibration
- [ ] Record ADC vs pressure data
- [ ] Implement conversion in firmware

---

## 5) EPC Pressure Command Table (Tuning)

**Status:** NOT TUNED YET

### Starting Point (Conservative):

| TPS (%)  | Pressure Command (%) | Notes |
|---|---|---|
| 0 | 40 | Idle / coast |
| 10 | 42 | Light cruise |
| 25 | 45 | Moderate throttle |
| 50 | 55 | Medium load |
| 75 | 65 | Heavy load |
| 100 | 75 | WOT (do NOT exceed ~75%) |

**Shift Bump:** +20% for 300ms during gear change

**Conversion to EPC Duty:**
```cpp
// Pressure Command % → EPC Duty %
// Inversion formula (exhaust-bleed EPC):
epc_duty = map(pressure_cmd, 0, 100, 60, 5);
// Pressure 0% (min) → EPC 60% duty (hard limit for thermal protection)
// Pressure 100% (max) → EPC 5% duty (near OFF = max pressure)
```

### Tuning Procedure (REQUIRES LINE PRESSURE GAUGE):
1. Start with fixed pressure command (e.g., 50%)
2. Measure actual line pressure with gauge
3. Adjust pressure command table until pressure is appropriate:
   - Idle: ~90-110 psi (minimum)
   - Light throttle: ~110-140 psi
   - Heavy throttle: ~140-180 psi
   - Shift bump: +20-40 psi during shift
4. Test shift quality on dyno or test road
5. Refine shift bump duration and magnitude

### Safety Rules:
- Never allow pressure to drop below ~80 psi under load (clutch slip)
- Harsh shifts are better than clutch slip
- Start conservative (high pressure), reduce gradually
- If in doubt, add more pressure

### TODO:
- [ ] Bench test EPC PWM output (scope verification)
- [ ] Install line pressure gauge
- [ ] Tune pressure table with data logging
- [ ] Refine shift bump timing

---

## 6) Downshift Speed Limits

**Status:** NOT TUNED YET

### Starting Point (Conservative):

| Gear | Maximum Vehicle Speed (mph) | Notes |
|---|---|---|
| 1st | 15 | Prevents over-rev on downshift |
| 2nd | 35 | Safe for most engines |
| 3rd | 60 | Rarely limited in practice |

**Logic:**
- If shifter commands downshift AND speed exceeds limit → BLOCK shift, hold current gear
- Display warning (if using dashboard UI)

### Tuning Based on Engine:
- Holden Alloytec 3.6L V6 redline: ~6500 RPM (verify with MS3)
- 4L60-E gear ratios:
  - 1st: 3.06:1
  - 2nd: 1.63:1
  - 3rd: 1.00:1
  - 4th: 0.70:1
- Final drive: ??? (measure or look up for your vehicle)

### Calculation:
```
Max safe speed (mph) = (Redline RPM × Tire diameter (in) × 0.002975) / (Gear ratio × Final drive)
```

### TODO:
- [ ] Verify final drive ratio
- [ ] Calculate actual downshift limits for your setup
- [ ] Update firmware constants
- [ ] Test downshift protection on dyno (safe environment)

---

## 7) TCC Lockup Thresholds

**Status:** NOT TUNED YET

### Starting Point (Conservative):

| Parameter | Value | Notes |
|---|---|---|
| Minimum gear | 3rd | Never lock in 1st/2nd |
| Minimum speed | 45 mph | Prevents stall at low speed |
| Maximum TPS | 20% | Unlock under heavy throttle |
| Lockup delay | 3 seconds | Prevents cycling after gear change |
| Unlock on TPS spike | >15% in 0.5s| Detects throttle transient (kickdown) |
| Over-temp inhibit | 130°C | Disable TCC if trans is overheating |

### TCC PWM Progressive Apply (Phase 4):
- Ramp TCC PWM duty from 0% → 80% over 800ms
- Smooth engagement prevents shudder
- Unlock: drop TCC PWM to 0% immediately, then turn off TCC enable

### Tuning Procedure:
1. Enable TCC in 4th gear only (safest)
2. Test lockup on flat road at 50 mph, light throttle
3. Monitor for shudder or harsh engagement
4. Adjust TCC PWM ramp rate and duration
5. Gradually expand enable conditions (3rd gear, lower speeds)

### TODO:
- [ ] Bench test TCC enable/disable logic
- [ ] Test TCC lockup on dyno first (controlled environment)
- [ ] Tune TCC PWM ramp rate on test drive
- [ ] Verify immediate unlock on brake input

---

## 8) Transmission Specifications (Vehicle-Specific)

**Record for reference:**

### Vehicle:
- Year: _____
- Make/Model: Holden (year/model?)
- Engine: Alloytec 3.6L V6
- ECU: MegaSquirt 3 + MS3X

### Transmission:
- Type: GM 4L60-E
- Year/Model: _____ (affects pressure switch logic, valve body calibration)
- Stock or modified: Stock valve body
- Torque converter: Stock or upgraded? _____

### Gear Ratios:
- 1st: 3.06:1
- 2nd: 1.63:1
- 3rd: 1.00:1
- 4th: 0.70:1

### Final Drive:
- Ratio: _____ (measure or look up)

### Tire Size:
- Diameter (inches): _____ (calculate VSS calibration)

### VSS:
- Pulses per mile: _____ (needed for speed calculation)
- Sensor type: VR (magnetic) or Hall-effect? _____

---

## Notes

**Safety First:**
- All initial testing should be done on a dyno or private test road
- Install a mechanical line pressure gauge BEFORE first test drive
- Start with conservative (high) pressure settings
- Test each phase incrementally (don't enable TCC until basic shifts work)

**Data Logging:**
- Log all sensor inputs, solenoid states, calculated values
- CSV format with timestamps
- Review logs after each test session
- Identify patterns before tuning

**Firmware Constants:**
Once calibrated, update these files:
- `firmware/config/config.h` (pressure tables, speed limits, TCC thresholds)
- `firmware/src/epc_control.cpp` (pressure command mapping)
- `firmware/src/tcc.cpp` (TCC enable logic)
- `firmware/src/state_machine.cpp` (downshift protection)

---

**Last Updated:** 2026-02-06 (initial template, no calibration data yet)

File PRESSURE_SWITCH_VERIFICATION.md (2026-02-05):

# Pressure Switch Verification Guide

**Purpose:** Verify the pressure switch truth table on YOUR transmission before relying on it for gear confirmation logic.

**Time Required:** ~15 minutes  
**Tools Needed:** Multimeter, notepad/phone for recording values

---

## ⚠️ Important Safety Notes

- **Engine OFF** for all tests
- **Key ON** (ignition on, engine not running) to power the transmission
- **Transmission in PARK** when starting
- **Parking brake engaged**
- **Vehicle on level ground**

---

## Understanding Pressure Switches

The 4L60-E has a **pressure switch manifold** inside the transmission valve body. It contains 3 switches (A, B, C) that close when hydraulic pressure is present in specific circuits.

**How it works:**
- The **shifter position** (P, R, N, D, 3, 2, 1) moves the **manual valve** inside the transmission
- The manual valve directs hydraulic pressure to different circuits
- Pressure closes switches → controller reads which position the shifter is in

**What it tells you:**
- ✅ Where the **shifter** is (manual valve position)
- ❌ NOT the actual gear the transmission is in (that's controlled by solenoids)

---

## Method 1: Using the TCM Controller (Preferred)

If you've already built the controller and uploaded the firmware:

### Step 1: Connect to Serial Monitor
1. Connect Teensy to computer via USB
2. Open Serial monitor (Arduino IDE, PlatformIO Serial Monitor, or `screen /dev/ttyACM0 115200`)
3. Set baud rate to **115200**

### Step 2: Power Up
1. Turn ignition to **ON** (do not start engine)
2. TCM will boot and display: `4L60E TCM boot`
3. Every 1 second, you'll see telemetry including:
   ```
   Manual Position: P/N (A:H B:L C:H)
   ```

### Step 3: Test Each Position
1. **With key ON, engine OFF:**
2. Move shifter slowly through each position: **P → R → N → D → 3 → 2 → 1**
3. Wait 2 seconds at each position for the reading to stabilize
4. Record the **Manual Position** and **switch states (A/B/C)** for each position

**Expected Pattern (OEM 4L60-E):**

| Shifter | Position Code | Switch A | Switch B | Switch C |
|---|---|---|---|---|
| **P** | P/N | H | L | H |
| **R** | R | L | L | H |
| **N** | P/N | H | L | H |
| **D** | D | H | L | L |
| **3** | 3 | H | H | L |
| **2** | 2 | H | H | H |
| **1** | 1 | L | H | H |

**Notes:**
- H = HIGH (switch open, no pressure)
- L = LOW (switch closed, pressure present)
- Park and Neutral read the same (H/L/H) — this is normal

### Step 4: Compare Results
- If all positions match the expected pattern → ✅ **OEM table confirmed, you're good to go**
- If some positions differ → ⚠️ **Update firmware with YOUR table** (see "Non-Standard Pattern" below)
- If all positions read the same → ❌ **Wiring fault or bad pressure switch manifold**

---

## Method 2: Using a Multimeter (No Controller Needed)

If you haven't built the controller yet, you can test with a multimeter:

### Step 1: Locate the Transmission Connector
1. Find the **20-pin connector** on the driver's side of the transmission case
2. It's usually near the shift solenoids (accessible from underneath)

### Step 2: Identify Pressure Switch Pins
Looking at the connector from the **wire side** (not the transmission side):

| Pin Label | Wire Color (typical) | Function |
|---|---|---|
| **N** | Often TAN or LT GRN  | Pressure Switch A |
| **R** | Often DK GRN | Pressure Switch B |
| **P** | Often LT BLU | Pressure Switch C |
| **GND** | BLACK (multiple) | Common Ground |

**⚠️ Wire colors vary by year/harness. Use a wiring diagram for YOUR vehicle if unsure.**

### Step 3: Measure Resistance
1. **Ignition OFF, key out**
2. **Disconnect the transmission connector** (unplug it from the trans)
3. Set multimeter to **Resistance (Ω)** mode
4. Measure between each switch pin and **ground** on the **transmission side** (not harness side)

**For each shifter position:**
1. Move shifter to position (P, R, N, D, 3, 2, 1)
2. Measure resistance from **Pin N** (Switch A) to ground
3. Measure resistance from **Pin R** (Switch B) to ground
4. Measure resistance from **Pin P** (Switch C) to ground

**Interpreting Results:**
- **0-5 Ω (near zero):** Switch CLOSED (pressure present) → reads as **LOW** in controller
- **Open/OL (infinite):** Switch OPEN (no pressure) → reads as **HIGH** in controller

**Expected Readings (OEM 4L60-E):**

| Shifter | Switch A (Pin N) | Switch B (Pin R) | Switch C (Pin P) |
|---|---|---|---|
| **P** | Open (HIGH) | 0Ω (LOW) | Open (HIGH) |
| **R** | 0Ω (LOW) | 0Ω (LOW) | Open (HIGH) |
| **N** | Open (HIGH) | 0Ω (LOW) | Open (HIGH) |
| **D** | Open (HIGH) | 0Ω (LOW) | 0Ω (LOW) |
| **3** | Open (HIGH) | Open (HIGH) | 0Ω (LOW) |
| **2** | Open (HIGH) | Open (HIGH) | Open (HIGH) |
| **1** | 0Ω (LOW) | Open (HIGH) | Open (HIGH) |

### Step 4: Record Results
Write down the actual resistance values you measured. If they match the expected pattern → you're good. If not → see "Non-Standard Pattern" below.

---

## Troubleshooting

### All Switches Read the Same (No Change with Shifter Movement)
**Possible causes:**
- Bad pressure switch manifold (common failure on high-mileage 4L60-E)
- Wiring harness fault (broken wire, corrosion)
- Transmission not receiving hydraulic pressure (pump not running, low fluid)

**Fix:**
- Replace pressure switch manifold (~$20-50 part)
- Check wiring continuity
- Check transmission fluid level

### Intermittent / Flickering Readings
**Possible causes:**
- Loose connector
- Corroded pins
- Worn manual valve or valve body

**Fix:**
- Clean connector with contact cleaner
- Check pin tension
- Inspect valve body (requires trans disassembly)

### One Switch Always Reads Wrong
**Possible causes:**
- Single switch failure inside manifold
- Broken wire for that specific switch
- Shorted wire (if always reads LOW)

**Fix:**
- Check wiring continuity for that switch
- Replace pressure switch manifold

---

## Non-Standard Pattern Detected

If your transmission's pressure switches don't match the OEM table, you have two options:

### Option 1: Update Firmware Truth Table (Recommended)
Edit `firmware/src/pressure_switches.cpp`, function `DecodePosition()`:

```cpp
ManualPosition PressureSwitches::DecodePosition(bool a, bool b, bool c) const {
  // YOUR VERIFIED TRUTH TABLE
  // Replace the patterns below with YOUR measured values
  
  if (a == HIGH && b == LOW && c == HIGH) {
    return ManualPosition::kParkNeutral;
  }
  // ... add your other positions here
}
```

Recompile and upload firmware.

### Option 2: Use Pressure Switches for Diagnostics Only
If the pattern is too inconsistent or non-standard, you can:
1. Leave the code as-is (will read `kUnknown` for most positions)
2. Use pressure switches only for **fault detection** (stuck switches, wiring faults)
3. Rely on **range selector inputs** (Pins 6/7/8/9) for gear selection instead

**Trade-off:**
- Range selector inputs tell you **shifter position** (reliable, direct wiring)
- Pressure switches tell you **hydraulic state** (diagnostic confirmation)
- For a manual-mode controller, range selector is primary; pressure switches are backup validation

---

## Recording Your Results

Use this template to document your transmission's truth table:

```
Transmission: GM 4L60-E
Year/Model: _______________
Date Verified: _______________
Tested By: _______________

┌────────┬──────────┬──────────┬──────────┐
│Shifter │ Switch A │ Switch B │ Switch C │
├────────┼──────────┼──────────┼──────────┤
│   P    │          │          │          │
│   R    │          │          │          │
│   N    │          │          │          │
│   D    │          │          │          │
│   3    │          │          │          │
│   2    │          │          │          │
│   1    │          │          │          │
└────────┴──────────┴──────────┴──────────┘

Notes:
_______________________________________________
_______________________________________________
```

**Save this data in:** `CALIBRATION_NOTES.md` (Section 2)

---

## After Verification

Once you've confirmed the truth table:

1. ✅ Update `CALIBRATION_NOTES.md` with your verified table
2. ✅ If non-standard, update `firmware/src/pressure_switches.cpp`
3. ✅ Remove the warning from `firmware/src/main.cpp` setup():
   ```cpp
   Serial.println("✅ Pressure switch truth table VERIFIED");
   ```
4. ✅ Mark as complete in `TODO.md`:
   ```
   - [x] **Pressure switches:** Truth table verified on trans
   ```

---

## Questions?

- **Can I skip this test?** Not recommended. Wrong truth table = wrong gear confirmation = potential safety issue.
- **What if I don't have a multimeter?** Use Method 1 (controller + Serial monitor) — easier anyway.
- **Do I need to start the engine?** No. Key ON is enough to power the solenoids and allow shifter movement.
- **Can I test in the car or on a lift?** Either works. Just make sure parking brake is engaged and wheels can't roll.

---

**Last Updated:** 2026-02-06

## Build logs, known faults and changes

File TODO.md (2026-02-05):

# TODO

## Phase 1 — Core Gear Control (bench testable)

- [ ] Read range selector inputs (1/2/3/D pins)
- [ ] Command SSA/SSB based on selected gear
- [ ] Fixed EPC duty (~10-15% = firm but not max pressure)
- [x] Serial logging of gear state and inputs (implemented: temp + pressure switches)
- [ ] Verify failsafe: SSA/SSB OFF on boot = 3rd gear
- [x] **Trans temp sensor:** Firmware implemented with lookup table
- [x] **Pressure switches:** Firmware implemented (OEM truth table, needs verification)

## Phase 2 — Speed Safety

- [ ] VSS interrupt capture and speed calculation
- [ ] Downshift protection (block 1st/2nd above safe speeds)
- [ ] VSS loss detection → hold current gear, raise pressure

## Phase 3 — Pressure Refinement

- [ ] TPS input scaling (5V → 3.3V divider)
- [ ] TPS-based EPC duty mapping (lower duty at higher load)
- [ ] Shift pressure bump (lower EPC duty during gear change)
- [ ] Configurable pressure tables

## Phase 4 — TCC Control

- [ ] TCC enable only in 3rd/4th gear
- [ ] Minimum speed threshold for TCC
- [ ] Brake switch → immediate TCC unlock
- [ ] TCC inhibit on high TPS / during shifts
- [ ] Delay timer before lockup (prevents cycling)
- [ ] Throttle transient detection → unlock
- [ ] Hysteresis on enable/disable thresholds
- [ ] TCC PWM progressive apply (ramp duty on lockup request)
- [ ] TCC PWM unlock sequence (PWM to 0% before enable OFF)

## Phase 5 — Hardening

- [ ] Sensor validation (TPS range, VSS sanity)
- [ ] Failsafe escalation paths
- [ ] Watchdog timer integration
- [ ] Transmission temp sensor input (optional)

---

## Hardware

- [x] Finalize solenoid driver schematic and BOM
- [x] **Brake switch verified** (+12V-switched, schematic is correct)
- [ ] **Select connectors** (Deutsch DTM or Amphenol Superseal — NOT GX20)
- [ ] Build driver board prototype
- [ ] Confirm pin mapping against Teensy 4.1 layout
- [ ] Decide VSS conditioning (VR → LM2903N comparator or Hall → direct)
- [ ] Power protection (TVS, reverse polarity, fusing)

## Tooling

- [ ] PlatformIO build/upload script
- [ ] Serial monitor with gear state display
- [ ] Basic logging to SD card (optional)

---

## Calibration (See CALIBRATION_NOTES.md & PRESSURE_SWITCH_VERIFICATION.md)

- [x] **Trans temp sensor:** OEM resistance values confirmed (3500Ω @ 20°C, 178Ω @ 100°C)
- [x] **Pressure switches:** OEM truth table confirmed (MegaShift documentation)
- [x] **Brake switch:** Confirmed +12V-switched (schematic correct)
- [ ] **Trans temp ADC:** Bench test ADC values at room temp, verify lookup table
- [ ] **Pressure switches:** ⚠️ CRITICAL - Physical verification on YOUR trans (see PRESSURE_SWITCH_VERIFICATION.md)
- [ ] **Line pressure sensor:** Install mechanical gauge, calibrate ADC vs psi (optional but recommended)
- [ ] **EPC pressure table:** Tune with line pressure gauge on dyno/test road
- [ ] **Downshift limits:** Calculate based on engine redline + gear ratios
- [ ] **TCC thresholds:** Tune lockup speed, delay, unlock conditions

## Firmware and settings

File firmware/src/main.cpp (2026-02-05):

#include <Arduino.h>

#include "board_config.h"
#include "epc_control.h"
#include "state_machine.h"
#include "tcc.h"
#include "vss.h"
#include "trans_temp.h"
#include "pressure_switches.h"

namespace {

tcm::EpcController epc;
tcm::VssSensor vss;
tcm::TccController tcc;
tcm::StateMachine state_machine;
tcm::TransTempSensor trans_temp;
tcm::PressureSwitches pressure_switches;

void ConfigurePins() {
 pinMode(hw::kPinSSA, OUTPUT);
 pinMode(hw::kPinSSB, OUTPUT);
 pinMode(hw::kPinTCC, OUTPUT);
 pinMode(hw::kPinEPC, OUTPUT);
 // TODO Phase 4: pinMode(hw::kPinTCCPWM, OUTPUT); for progressive TCC apply

 pinMode(hw::kPinRange1, INPUT_PULLUP);
 pinMode(hw::kPinRange2, INPUT_PULLUP);
 pinMode(hw::kPinRange3, INPUT_PULLUP);
 pinMode(hw::kPinRangeD, INPUT_PULLUP);

 pinMode(hw::kPinBrake, INPUT_PULLUP);
 pinMode(hw::kPinWatchdogEnable, INPUT_PULLUP);

 pinMode(hw::kPinVSS, INPUT);
 pinMode(hw::kPinRPM, INPUT);
}

void ApplySafeOutputs() {
  digitalWrite(hw::kPinSSA, LOW);
  digitalWrite(hw::kPinSSB, LOW);
  digitalWrite(hw::kPinTCC, LOW);
  analogWrite(hw::kPinEPC, 0); // 0% duty = max pressure (project assumption).
}

} // namespace

void setup() {
 ConfigurePins();
 ApplySafeOutputs();
 epc.Init();
 vss.Init();
 tcc.Init();
 state_machine.Init();
 trans_temp.Init();
 pressure_switches.Init();
 
 Serial.begin(115200);
 while (!Serial && millis() < 3000) {
 delay(10);
 }
 Serial.println("4L60E TCM boot");
 Serial.println("⚠️  WARNING: Pressure switch truth table NOT VERIFIED");
 Serial.println("    Verify switch patterns before relying on gear confirmation");
}

void loop() {
 // TODO: Replace with state machine execution.
 static uint32_t last_log_ms = 0;
 const uint32_t now_ms = millis();
 
 // Update all sensors
 vss.Update();
 tcc.Update();
 epc.Update();
 trans_temp.Update();
 pressure_switches.Update();
 
 // Prepare state machine context
 tcm::StateContext ctx{};
 ctx.now_ms = now_ms;
 ctx.sensor_fault = !trans_temp.IsValid() || !pressure_switches.IsValid();
 
 state_machine.Update(ctx);
 
 // Periodic telemetry logging (every 1 second)
 if (now_ms - last_log_ms >= 1000) {
  last_log_ms = now_ms;
  
  // Log temperature
  if (trans_temp.IsValid()) {
   Serial.print("Trans Temp: ");
   Serial.print(trans_temp.GetTempCelsius());
   Serial.print("°C (");
   Serial.print(trans_temp.GetTempFahrenheit());
   Serial.print("°F)");
   if (trans_temp.IsOverTemp()) {
    Serial.print(" ⚠️  OVER-TEMP");
   }
   Serial.println();
  } else {
   Serial.println("Trans Temp: FAULT");
  }
  
  // Log pressure switches
  Serial.print("Manual Position: ");
  Serial.print(tcm::ManualPositionToString(pressure_switches.GetPosition()));
  
  bool sw_a, sw_b, sw_c;
  pressure_switches.GetRawSwitches(sw_a, sw_b, sw_c);
  Serial.print(" (A:");
  Serial.print(sw_a ? "H" : "L");
  Serial.print(" B:");
  Serial.print(sw_b ? "H" : "L");
  Serial.print(" C:");
  Serial.print(sw_c ? "H" : "L");
  Serial.print(")");
  
  if (!pressure_switches.IsValid()) {
   Serial.print(" ⚠️  INVALID PATTERN");
  }
  Serial.println();
  
  Serial.println("---");
 }
 
 delay(10);
}

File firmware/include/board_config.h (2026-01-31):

#pragma once

#include <stdint.h>

// Central pin map and hardware constants.

namespace hw {

constexpr uint8_t kPinSSA = 2;
constexpr uint8_t kPinSSB = 3;
constexpr uint8_t kPinTCC = 4;
constexpr uint8_t kPinEPC = 5;
constexpr uint8_t kPinTCCPWM = 12;

constexpr uint8_t kPinRange1 = 6;
constexpr uint8_t kPinRange2 = 7;
constexpr uint8_t kPinRange3 = 8;
constexpr uint8_t kPinRangeD = 9;

constexpr uint8_t kPinBrake = 10;
constexpr uint8_t kPinWatchdogEnable = 11;

constexpr uint8_t kPinTPS = 14; // A0
constexpr uint8_t kPinTransTemp = 15; // A1
constexpr uint8_t kPinLinePressure = 16; // A2

constexpr uint8_t kPinVSS = 18;
constexpr uint8_t kPinRPM = 19;

// Pressure switch manifold (gear confirmation)
constexpr uint8_t kPinPressureSwitchA = 20;
constexpr uint8_t kPinPressureSwitchB = 21;
constexpr uint8_t kPinPressureSwitchC = 22;

} // namespace hw

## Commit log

2026-01-24 Clarify EPC failsafe and update docs
    [main.cpp]
2026-01-24 Fix EPC direction docs and add consolidated BOM
    - Fix EPC duty/pressure relationship in reference docs
    (higher duty = lower pressure, 0% = max pressure failsafe)
    - Add consolidated BOM_LIST.md with DIY-friendly parts
    - Include optional signal conditioning parts (74HC14, PC817, LM358)
2026-01-24 Add EPC/TCC technical details from DieselHub and FuelTech
    - Add 60% duty ceiling as hard limit (thermal/hydraulic protection)
    - Add EPC current context: 0-1.1A where 0A = max pressure
    - Note SSA/SSB OFF = intentional GM limp mode (3rd gear)
    - Add TCC delay timer, hysteresis, and transient detection
    - Add explicit 0% EPC duty triggers (reset, sensor loss, overtemp)
    - Expand TODO.md Phase 4 with TCC implementation details
    - Add 4l60e_info.txt with extracted FuelTech/DieselHub facts
2026-01-25 Update BOM parts and add datasheets
    - Substitute MOSFET: IRLZ44N → STP36NF06L (AEC-Q101 automotive qualified)
    - Substitute TVS: 1.5KE36CA → 5KP36CA (5000W peak pulse power)
    - Substitute VR conditioner: LM1815 → LM2903N (with bias circuit schematic)
    - Add pressure switch manifold pins (20-22) to board_config.h and HARDWARE.md
    - Remove optional PC817 opto and LM358 op-amp from BOM (not needed)
    - Update brake/TPS input conditioning notes (simple dividers sufficient)
    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
    [shop_list.xlsx]
2026-02-05 Add trans temp sensor and pressure switch firmware modules + calibration docs
    - Implemented trans temp sensor with OEM GM 4L60-E lookup table
    - Implemented pressure switch manifold reading with OEM truth table
    - Added telemetry logging to main firmware
    - Created CALIBRATION_NOTES.md with confirmed OEM sensor data
    - Created PRESSURE_SWITCH_VERIFICATION.md testing guide
    - Updated BOM component count (0.1uF caps: 11 total)
    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
